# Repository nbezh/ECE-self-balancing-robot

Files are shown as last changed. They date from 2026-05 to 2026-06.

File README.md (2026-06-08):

# Self-Balancing Robot (ESP32)

A two-wheeled self-balancing robot built on an ESP32. The robot keeps itself
upright with a complementary-filter angle estimate feeding a PID controller,
and exposes a WiFi access-point web page for live gain tuning. The firmware is
structured as a set of FreeRTOS tasks.

## Hardware

| Component | Part |
|---|---|
| MCU | ESP32 DevKit (WROOM) |
| Motor driver | TB6612FNG (dual H-bridge) |
| IMU | MPU6050 (GY-521) |
| Distance sensor  | HC-SR04 ultrasonic |
| Motors | TT gearmotors (2x) |
| Power | 8 V pack -> 5 V buck converter|

The IMU is mounted vertically between the wheels; the battery sits high, which
raises the centre of mass and makes the robot tip more slowly (easier to
control).

### Pin map

| Signal | GPIO | Notes |
|---|---|---|
| TB6612 PWMA | 4 | Motor A speed |
| TB6612 AIN2 | 16 | Motor A direction |
| TB6612 AIN1 | 17 | Motor A direction |
| TB6612 BIN1 | 18 | Motor B direction |
| TB6612 BIN2 | 19 | Motor B direction |
| TB6612 PWMB | 23 | Motor B speed |
| TB6612 STBY | 5 | Driver enable. **10 kΩ pulldown to GND** |
| MPU6050 SDA | 21 | I2C (addr 0x68, AD0 -> GND) |
| MPU6050 SCL | 22 | I2C |
| HC-SR04 TRIG | 26 | Direct |
| HC-SR04 ECHO | 25 | **Via 1 kΩ / 2 kΩ divider (5 V -> 3.3 V)** |

GPIO5 is a strapping pin that boots HIGH, so the pulldown keeps the motor
driver disabled at power-up until firmware enables it.

### Power

`8 V -> buck -> 5 V` rail feeds the ESP32 `VIN`, the TB6612 `VM` (motor power),
and the HC-SR04. The ESP32's onboard 3.3 V regulator feeds the TB6612 `VCC`
(logic) and the MPU6050. All grounds are common. A 470–1000 µF bulk capacitor
on the 5 V rail absorbs motor current spikes so the ESP32 doesn't brown out.

> Set the buck to exactly 5.0 V (meter it with the output disconnected) before
> wiring it to the ESP32. Don't power from USB and the buck simultaneously.

## Software

### Build

PlatformIO project. `platformio.ini`:

```ini
[env:esp32dev]
platform = espressif32
board = esp32dev
framework = arduino
monitor_speed = 115200
lib_deps =
    ESP32Async/ESPAsyncWebServer
    ESP32Async/AsyncTCP
build_flags =
    -D CONFIG_ASYNC_TCP_RUNNING_CORE=0
    -D CONFIG_ASYNC_TCP_STACK_SIZE=16384
```

The PWM layer auto-selects the correct LEDC API for ESP32 Arduino core 2.x or
3.x, so it builds on either.

### Run

1. Flash `src/main.cpp`.
2. Connect a phone/laptop to the WiFi network **`BalanceBot`** (password
   `balance123`).
3. Open `http://192.168.4.1`.
4. The robot boots **STOPPED**. Hold it near upright, press **GO** to arm.

The page shows a live angle graph and the latest ultrasonic distance, plus
sliders for Kp, Ki, Kd, balance offset, and the motor deadband. **Save to
flash** persists the current gains (NVS).

## RTOS architecture

The ESP32 Arduino core runs on FreeRTOS, so the firmware is split into three
tasks with explicit priorities and core affinity rather than a single
`loop()`. This separates the one hard-real-time activity (balancing) from the
soft-real-time ones (networking, ranging).

| Task | Core | Priority | Rate | Job |
|---|---|---|---|---|
| `controlTask`  | 1 | 3 (high) | 200 Hz  | MPU read → complementary filter → PID → motors |
| `commsTask` | 0 | 1 | 25 Hz | Push telemetry to the web page |
| `distanceTask` | 0 | 1 | 10 Hz | Read HC-SR04 (`pulseIn`) |

**Deterministic control timing.** `controlTask` uses `vTaskDelayUntil`, which
schedules each iteration on a fixed period instead of "delay N ms after the
work finishes." This gives a constant control interval (`dt = 5 ms`), so the
filter and PID math use a fixed timestep instead of a measured, jittery one.

**Core isolation.** The control task is pinned alone to core 1. The WiFi stack
and the other two tasks live on core 0. Nothing on core 0 can steal time from
the balance loop.

**Why `distanceTask` exists.** `pulseIn()` is a *blocking* call that can stall
for up to 30 ms waiting for the ultrasonic echo. In a single-loop design that
stall would wreck the 200 Hz control timing. Isolating it in its own
low-priority task on core 0 means the blocking read can never disturb
balancing — a concrete demonstration of why task separation matters.

**Synchronization.** All shared data (gains, current angle, run flag, distance)
lives in one `State` struct guarded by a mutex (`stMutex`). Each task takes the
mutex only long enough to *snapshot* values into local variables, then releases
it before doing slow work (motor writes, `ws.textAll()`, `pulseIn`). Critical
sections stay short, so no task blocks another, and there is no nested locking
(no deadlock risk).

```
                 +---------------------+
   web sliders → |  stMutex-guarded    | → controlTask reads gains
                 |  State struct       |
   controlTask → |  (gains, angle,     | → commsTask reads angle/dist
   distanceTask →|   run, distance)    |
                 +---------------------+
```

## Tuning

1. Set the **Offset** to the robot's true balance point: with motors stopped,
   find the angle where it balances on its own on the wheels, read that value
   off the page, and enter it. Usually 1–3°.
2. Set **Min PWM** to the motor deadband — the smallest PWM that actually turns
   the wheels (TT motors ignore small commands below this, so corrections do
   nothing without it).
3. Raise **Kp** until the robot makes firm, quick corrections; add **Kd**
   (~1.0) to damp overshoot; add a little **Ki** last, only if it holds a
   steady lean.

## Known limitations

TT (yellow) gearmotors are marginal for balancing: they have a deadband, gear
backlash, and limited top speed. The deadband compensation helps, but these
motors may set a hard ceiling on how well any tuning can balance the robot.

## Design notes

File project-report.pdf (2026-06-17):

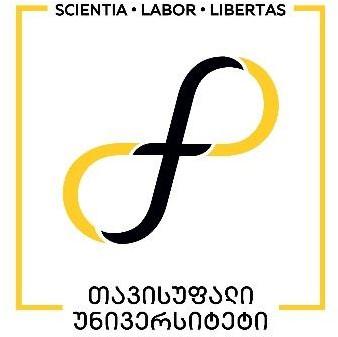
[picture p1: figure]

## თბილისის თავისუფალი უნივერსიტეტი

## კომპიუტერული მეცნიერებების, მათემატიკისა და ინჟინერიის

## სკოლა (MACS[E])

### ელექტრო და კომპიუტერული ინჟინერიის პროგრამა

ბეჟანიშვილი ნიკოლოზ
ცხვედაძე ქეთევანი

ელექტრო და კომპიუტერული ინჟინერიის ლაბორატორია - პროექტის ანგარიში თვითბალანსირებადი რობოტი

თბილისი

2026

ii

## Annotation

This project was completed as part of the “Electrical and Computer Engineering Laboratory”

course. The objective was to design and build a two-wheeled self-balancing robot - a physical

implementation of the inverted pendulum control problem.

The robot uses an MPU6050 six-axis IMU to measure tilt. A complementary filter fuses the

accelerometer and gyroscope readings to estimate the lean angle at 200 Hz. A PID controller converts the

angle error into motor commands delivered to two motored wheels. The firmware is organized as three

concurrent RTOS tasks running across the ESP32’s two cores, separating the hard-real-time balance loop

from soft-real-time networking and sensor tasks. Additional features include HC-SR04 ultrasonic distance

sensing, battery voltage monitoring, and NVS-based persistent gain storage. A WiFi access point exposes

a web interface for live angle telemetry, real-time gain tuning (Kp, Ki, Kd, offset), remote drive control,

and battery voltage display. All primary objectives were achieved: the robot balances stably and all

parameters can be tuned in real time without rebooting.

### ანოტაცია

ეს პროექტი შესრულდა კურსის „ელექტრო და კომპიუტერული ინჟინერიის

ლაბორატორია“ ფარგლებში. პროექტის მიზანი იყო ორბორბლიანი თვითბალანსირებადი

რობოტის შექმნა.

რობოტი იყენებს MPU6050 ექვსღერძიან IMU-ს დახრის გასაზომად. კომპლემენტარული

ფილტრი აერთიანებს აქსელერომეტრისა და გიროსკოპის მონაცემებს 200Hz სიხშირით დახრის

კუთხის შესაფასებლად. PID კონტროლერი კუთხის გადახრის საფუძველზე ატრიალებს ძრავებს

ბალანსის შენარჩუნებლად. პროგრამა სამ პარალელურ RTOS Task-ად არის ორგანიზებული.

WiFi | წვდომის წერტილი | უცრუნველყოფს | ვებ-ინტერფეისს | ტელემეტრიით, | PID-ის

პარამეტრების რეალურ დროში დარეგულირების შესაძლებლობით და დისტანციური მართვით.

ყველა მთავარი მიზანი მიღწეული იქნა.

iii

## Table Of Contents

## Table of Figures

## Introduction

This project was completed as the self-balancing robot assignment for the Electrical and

Computer Engineering Laboratory course at Tbilisi Free University. The goal was to design, build,

and program a two-wheeled self-balancing robot that demonstrates key embedded systems

concepts: sensor fusion, closed-loop control, real-time scheduling, and wireless human-machine

interface design.

The robot is mechanically analogous to a Segway: two driven wheels on a common axle

support a vertical chassis. Without active control, the structure is unstable and will topple. Balance

is maintained by continuously reading the tilt angle from an MPU6050 inertial measurement unit

(IMU), fusing accelerometer and gyroscope measurements through a complementary filter at 200

Hz, and driving TT gearmotors through a TB6612FNG dual H-bridge in the direction that corrects

the lean. The control law is a PID (Proportional-Integral-Derivative) controller.

The firmware runs on an ESP32 microcontroller using the FreeRTOS real-time operating

system, structured as three concurrent tasks with explicit priority and core affinity. The balance-

critical task is isolated on one CPU core; networking and ranging tasks run on the other. This

prevents any soft-real-time activity from disturbing the 5ms control interval.

The robot exposes a WiFi access point. Connecting a phone or laptop to it opens a web

dashboard that shows a live angle graph, the current ultrasonic distance reading, battery voltage,

and sliders for all tunable parameters. Gains can be saved to ESP32 NVS flash so they persist across

power cycles. The chassis was designed in CAD and produced using 3D printing and laser-cut

plywood.

The project had the following requirements:

- Correct Scheme / Wiring: Correctly wiring ESP32, MPU6050, Driver and batteries are

correctly wired.

- Frame and CAD Design: The robot has a systemic construction; the center of mass is

correctly placed and a CAD design of the robot is present.

- Sensor Reading: Reliably reading calibrated values from the MPU6050
- Filtering and Calculating Angle: Filtering IMU data and reliably calculating the lean

angle.

- PID Controller and Tuning: The robot holds balance when turned on and can restore

balance after a small push.

- Radio Control: Remote control using ESP32’s WiFi/Bluetooth, stable connection and

control.

- Object Detection and Avoidance: Detecting object in front using a distance measuring

sensor and avoiding them despite radio commands.

- Telemetry: The remote controller displays the battery charge level, current lean angle

and RSSI WiFi/Bluetooth signal level in real-time.

An additional requirement is that object avoidance and telemetry should run on a separate thread

independent of the control loop using RTOS.

## Technical Review

Physical Design

The chassis is a combination of 3D-printed structural parts and laser-cut plywood for outer

frame. CAD files and G-code are included in the repository under the CAD Files/, 3D Printing/,

and Laser/ subdirectories. The two TT gearmotors are mounted symmetrically on either side of

the lower chassis plate. We mounted MPU6050 IMU between the wheels in a vertical orientation

aligned with the robot’s axis of balance to minimize the error caused by the centripetal and tangential

accelerations. We positioned the battery pack at the top of the chassis. This placement is intentional:

raising the center of mass makes the robot tip more slowly, giving the PID loop more time to react

to disturbances. The power system uses two Li-ion batteries (3.7V nominal, 4.2V max) wired in series

via BMS. The voltage is stepped down to 5 V via a buck converter for ESP and the ultrasonic sensor.

The ESP32’s on-board 3.3 V linear regulator powers the TB6612FNG logic supply (VCC) and the

MPU6050.

We designed the frame in a way that allows for easy assembly using box joints. There are dedicated

holes for wires, switch, motor axis, etc. The files for each piece are stored as individual parts, the full outer

frame of the bot uses these parts and is stored as an assembly and the complete assembly of the bot includes

the frame as well as other hardware. This allows for easier file management and simplifies making changing

due to the architecture of SolidWorks.

### IMU & Angle Estimation

The MPU6050 (GY-521 breakout) is a six-axis IMU providing a three-axis accelerometer

and three-axis gyroscope over I2C. It is powered by the ESP32’s 3.3 V regulator with SDA on

GPIO 21 and SCL on GPIO 22. The AD0 pin is tied to GND, setting the I2C address to 0x68. The

INT, XDA, and XCL pins are left unconnected.

On startup, a gyroscope calibration routine runs while the robot is held stationary. It takes

a fixed number of readings and computes the mean gyroscope output on each axis. These offsets

are subtracted from all subsequent gyro readings, removing static drift bias.

Angle estimation uses a complementary filter. The accelerometer provides an absolute tilt

angle derived from the gravity vector projection, but is noisy due to vibration and motor-induced

acceleration. The gyroscope provides a smooth rate signal that integrates to angle, but accumulates

drift over time. The complementary filter combines both at a fixed 5 ms interval:

angle = α ∗ (angle + gyrorate ∗ dt) + (1 − α) ∗ accel_angle

Where α = 0.98 is the high-pass weight on the gyro path and dt = 5 ms. The filter trusts

the gyroscope for fast dynamics and the accelerometer for slow drift correction. The controlTask

uses vTaskDelayUntil, scheduling each wake-up on a fixed absolute deadline so that dt is exactly

constant regardless of how long the sensor read and math take

### PID Balance Controller

The PID controller runs every 5 ms in controlTask. It computes a motor output from the

angle error as follows:

error = measured_angle − setpoint

integral+= error × dt

output = Kp ∗ error + Ki ∗ integral + Kd ∗

error − preverror
dt

The setpoint (balance offset) compensates for asymmetric component placement where

the robot’s true center of mass does not coincide with the geometric axis. It is calibrated by holding

the robot near vertical, reading the stabilized angle from the web interface, and entering that

value as the offset.

TT gearmotors have a significant stiction deadband: small PWM commands below a

threshold produce no movement due to motor friction and gear backlash. The deadband

compensation adds the configured minimum PWM value to any non-zero output before sending

it to the driver, ensuring that even small corrective commands produce actual wheel movement.

All gains, the balance offset, and the deadband value are stored in the mutex-protected shared

State struct and can be changed via the web interface with immediate effect.

### WiFi Control & Telemetry Interface

The ESP32 operates as a WiFi access point (SSID: BalanceBot, password: balance123),

requiring no external router. ESPAsyncWebServer and AsyncTCP serve a single-page

HTML/JavaScript dashboard at 192.168.4.1 over WebSocket.

The dashboard features a live angle graph updated in real time, the latest ultrasonic

distance reading, battery voltage, sliders for Kp, Ki, Kd, balance offset, and motor deadband, a

GO/STOP button to arm or disarm the balance loop, a Save to Flash button that writes current

gains to ESP32 NVS for persistence across power cycles, and forward/backward drive buttons that

temporarily shift the balance setpoint to command the robot to lean and move.

The commsTask runs at 25 Hz on Core 0, pushing JSON telemetry snapshots to all

connected WebSocket clients. The mutex is held only briefly to copy the current state into local

variables, then released before the WebSocket send, keeping the critical section short.

We used a resistor voltage divider to step the 8.4V battery voltage down into the 0–3.3 V

range readable by the ESP32 ADC. GPIO 35 is used as the ADC input because it is a dedicated

input-only pin with no alternate function conflicts, making it ideal for analog sensing. The divider

is calculated so that the maximum expected battery voltage (nominally 8.4 V for a two-cell lithium

pack at full charge) maps to approximately 3.1 V at the ADC input, staying within the 3.3 V rail

with margin. The ADC reading is converted back to battery voltage by the inverse of the divider

ratio and sent to the web dashboard as part of the commsTask telemetry. We found the values of

47kΩ and 100kΩ to work best for our purposes.

### Distance Detection & Object Avoidance

We used the HC-SR04 Ultrasonic sensor for distance measurement. It measures distance

by emitting a 10 µs pulse on the TRIG pin and timing the return echo on the ECHO pin. Distance

is calculated as:

distance = duration ×

0.034
2
giving the result in centimetres. A pulseIn timeout of 30,000 µs prevents indefinite

blocking when no echo returns.

The HC-SR04 ECHO pin outputs 5V logic. GPIO 25 is protected by a 1 kΩ / 2 kΩ resistor

voltage divider that scales the 5 V echo signal down to approximately 3.3 V before it reaches the

ESP32 input. The pulseIn() call is blocking and can stall for up to 30 ms. In a monolithic loop

design this would destroy the 200 Hz control timing. The solution is to isolate ranging in a

dedicated FreeRTOS task (distanceTask) running at 10 Hz on Core 0 at low priority. The measured

distance is stored in the shared State struct under the mutex, and the control task reads only the

cached value without ever blocking

### FreeRTOS Firmware Architecture

The ESP32 Arduino core runs on FreeRTOS. Rather than a monolithic loop(), the firmware

is organized into three explicit tasks with defined priorities and core affinity, separating the one

hard-real-time activity (balance control) from soft-real-time activities (networking, ranging):

Task | Core | Priority | Rate | Responsibility
controlTask | 1 | 3 (high) | 200 Hz | MPU read → complementary filter → PID → motor output
commsTask | 0 | 1 | 25 Hz | JSON telemetry push to WebSocket clients
distanceTask | 0 | 1 | 10 Hz | HC-SR04 ranging (blocking pulseIn call)

Deterministic control timing is achieved by vTaskDelayUntil in controlTask, which

schedules each wake-up on an absolute tick deadline. This gives a constant dt = 5ms regardless

of how long the IMU read and PID math take. Core isolation pins controlTask alone to Core 1;

nothing on Core 0 can preempt the balance loop.

All shared data lives in a single State struct: the gain values, current angle, armed/run flag,

and ultrasonic distance. The struct is protected by a FreeRTOS mutex (stMutex). Each task

acquires the mutex only long enough to snapshot values into local variables, then releases it before

any slow operation (motor writes, WebSocket sends, pulseIn). This keeps critical sections short

and eliminates nested locking, making deadlock impossible.

## Conclusion

All requirements were met. The robot maintains balance using a complementary filter

angle estimate feeding a PID controller, with all parameters accessible and tunable in real time

through a WiFi web interface without reflashing.

Several engineering challenges were encountered and addressed during development.

Gyroscope drift was mitigated by the startup calibration routine and the complementary filter’s

low-frequency correction from the accelerometer. The blocking nature of pulseIn() was addressed

by isolating ranging in a dedicated low-priority RTOS task so it cannot affect control timing.

The primary hardware limitation of the system is the TT gearmotors. These motors have a

noticeable stiction deadband, gear backlash, and limited maximum speed. The deadband

compensation in the firmware partially addresses the stiction, but gear backlash introduces a

mechanical hysteresis that the control loop cannot fully compensate. Encoderless operation means

there is no closed-loop speed or position feedback at the motor level, which sets a ceiling on

achievable balance quality regardless of PID tuning.

The most valuable learning outcome was the end-to-end design of a real-time embedded

system: understanding how blocking I/O operations must be isolated from time-critical loops, how

shared state must be protected with mutexes in concurrent firmware, and how physical

phenomena (center-of-mass placement, motor stiction, ADC scaling) must be accounted for at

both the hardware and firmware level. The project also provided practical PID tuning experience,

where the interaction between Kp, Kd, and the mechanical deadband became directly observable

through the live web interface.

## Skills and Technologies

- Visual Studio Code (with PlatformIO for ESP programming)
- SolidWorks for CAD design.
- CorelDRAW for editing vector cut designs.
- Programming/markup languages: C++, HTML.
- ESP32 microcontroller programming (C++, Arduino framework, PlatformIO)
- Real-time system design with WebSocket.
- ESPAsyncWebServer and AsyncTCP for WiFi access point and WebSocket server.
- NVS (Non-Volatile Storage) for persistent parameter storage across power cycles.
- FreeRTOS: multi-task firmware design, task priorities, core affinity, vTaskDelayUntil.
- Mutex synchronization for shared state in concurrent firmware
- I2C communication protocol for MPU6050.
- Complementary filter design for IMU sensor fusion
- PID controller design, implementation, and empirical tuning
- Laser Cutting machine competence for cutting out and engraving various designs
- Cable management and labeling, designing maintainable and easily replicable modular systems.
- Physical assembly skills: Soldering, wood cutting & gluing
- Git version control and GitHub repository management with meaningful commit conventions
- Hardware debugging: multimeter use, serial monitor diagnostics, pin conflict resolution

## Individual contributions

Nikoloz Bezhanishvili:

- Mechanical chassis design using SolidWorks
- 3D printing and laser cutting
- Physical assembly, component mounting, and cable management
- Motor mounting and mechanical alignment
- Hardware soldering and wiring
- Project testing, PID tuning, and demonstration preparation
- GitHub repository setup and commit management
- Research
- Project report writing

Ketevani Tskhvedadze:

- Full ESP32 firmware architecture (FreeRTOS task structure, shared State, mutex)
- MPU6050 driver, gyroscope calibration, and complementary filter implementation
- PID controller design and implementation with deadband compensation
- ESPAsyncWebServer WiFi access point and web dashboard (live graph, sliders, drive

control)

- HC-SR04 object detection and avoidance (distanceTask, voltage-divider level shift)
- Battery voltage monitoring circuit (GPIO 35 divider) and firmware integration
- NVS gain persistence implementation
- Hardware soldering and wiring, sensor integration, and debugging
- Research
- Project report writing

## GitHub repository

All source code, CAD files, 3D printing G-code, and laser-cut files for this project are publicly

available on GitHub. The repository is organized into the following subdirectories:

- self-balancing-code/ — PlatformIO project with full C++ firmware
- CAD Files/ — CAD design files for the chassis
- 3D Printing/ — G-code files for 3D-printed structural parts
- Laser/ — Files for laser-cut flat panels

Repository: https://github.com/nbezh/ECE-self-balancing-robot

Contributors’ profiles:

Nikoloz Bezhanishvili – https://github.com/nbezh

Ketevani Tskhvedadze - https://github.com/tskhvedadzee

## References

Datasheets & Component Information:

[1] TDK InvenSense, “MPU-6000 and MPU-6050 Product Specification,” Datasheet. [Online]. Available: https://invensense.tdk.com/wp-content/uploads/2015/02/MPU-6000-Datasheet1.pdf.
[2] Toshiba Semiconductor, “TB6612FNG Dual DC Motor Driver IC,” Datasheet. [Online]. Available: https://www.alldatasheet.com/datasheet-pdf/pdf/209390/TOSHIBA/TB6612FNG.html.
[3] Multicomp, “HC-SR04 Ultrasonic Ranging Module Datasheet,” Alldatasheet. [Online]. Available: https://www.alldatasheet.com/datasheet-pdf/pdf/2216428/MULTICOMP/HC-SR04.html.
[4] Espressif Systems, ESP32 Technical Reference Manual. [Online]. Available: https://documentation.espressif.com/esp32_technical_reference_manual_en.pdf.

Software & Frameworks:

[5] FreeRTOS, “FreeRTOS Kernel Documentation,” FreeRTOS.org. [Online]. Available: https://www.freertos.org/Documentation/01-FreeRTOS-quick-start/01-Beginners-guide/01-RTOSfundamentals. (https://www.freertos.org/Documentation/01-FreeRTOS-quick-start/01-Beginners-guide/01-RTOS-fundamentals)
[6] ESP32Async, “ESPAsyncWebServer,” GitHub. [Online]. Available: https://github.com/ESP32Async/ESPAsyncWebServer.
[7] “PlatformIO Latest Documentation,” PlatformIO. [Online]. Available: https://docs.platformio.org/en/latest/.

Articles & Resources:

[8] Espressif Systems, “Non-Volatile Storage (NVS) Library,” ESP-IDF Documentation. [Online]. Available: https://docs.espressif.com/projects/esp-idf/en/latest/esp32/apireference/storage/nvs_flash.html. (https://docs.espressif.com/projects/esp-idf/en/latest/esp32/api-reference/storage/nvs_flash.html)

GrabCAD 3D Models:

[9] "Perfboard," GrabCAD. [Online]. Available: https://grabcad.com/library/perfboard-1.
[10] "ESP32 DevKit V1 3D Model," GrabCAD. [Online]. Available: https://grabcad.com/library/esp32-devkit-v1-3d-model-1.
[11] "TB6612FNG Driver," GrabCAD. [Online]. Available: https://grabcad.com/library/tb6612fngdriver-1. (https://grabcad.com/library/tb6612fng-driver-1)
[12] "MPU6050 Accelerometer Module," GrabCAD. [Online]. Available: https://grabcad.com/library/mpu6050-accelerometer-module-1.

[13] "HC-SR04 Ultrasonic Sensor," GrabCAD. [Online]. Available: https://grabcad.com/library/hc-sr04-ultrasonic-sensor-10. (https://grabcad.com/library/hc-sr04-ultrasonic-sensor-10)
[14] "Boitier 2 Accus 18650 / 2 Slots 18650 Battery Holder," GrabCAD. [Online]. Available: https://grabcad.com/library/boitier-2-accus-18650-2-slots-18650-battery-holder-1.
[15] "Generic 18650 Battery," GrabCAD. [Online]. Available: https://grabcad.com/library/generic-18650-battery-2. (https://grabcad.com/library/generic-18650-battery-2)
[16] "TT Motor Dual Shaft," GrabCAD. [Online]. Available: https://grabcad.com/library/tt-motordual-shaft-1. (https://grabcad.com/library/tt-motor-dual-shaft-1)
[17] "TT Motor Wheel Yellow," GrabCAD. [Online]. Available: https://grabcad.com/library/tt-motor-wheel-yellow-1. (https://grabcad.com/library/tt-motor-wheel-yellow-1)
[18] "Switch On Off White," GrabCAD. [Online]. Available: https://grabcad.com/library/switch-onoff-white-1. (https://grabcad.com/library/switch-on-off-white-1)

## Attachments & Project Visuals

Table 1: ESP connections

GPIO Board Label | Connected To | Module | Voltage
4 | D4 | TB6612 PWMA | Motor Driver | 3.3V out (PWM)
5 | D5 | TB6612 STBY + 10 kΩ to GND | Motor Driver | 3.3V out
16 | D16 | TB6612 AIN2 | Motor Driver | 3.3V out
17 | D17 | TB6612 AIN1 | Motor Driver | 3.3V out
18 | D18 | TB6612 BIN1 | Motor Driver | 3.3V out
19 | D19 | TB6612 BIN2 | Motor Driver | 3.3V out
23 | D23 | TB6612 PWMB | Motor Driver | 3.3V out (PWM)
21 | D21 | MPU6050 SDA | IMU | 3.3V (I2C)
22 | D22 | MPU6050 SCL | IMU | 3.3V (I2C)
26 | D26 | HC-SR04 TRIG | Distance | 3.3V out
25 | D25 | HC-SR04 ECHO via 1 kΩ/2 kΩ divider | Distance | 3.3V in
35 | D35 (input only) | Battery voltage divider output | Power Monitor | 3.3V in (ADC)
3V3 | 3V3 | MPU6050 VCC, TB6612 VCC | Power | 3.3V source
VIN | VIN | TB6612 VM, HC-SR04 VCC | Power | 5V source
GND | GND | All component GNDs | Power | Ground

Table 2: MPU6050 IMU connections

Pin/Signal | ESP32 GPIO | Notes
VCC | 3V3 | 3.3V supply. MUST be 3.3V; 5V will damage the module
GND | GND | Common ground
SCL | GPIO 22 | I2C clock
SDA | GPIO 21 | I2C data
AD0 | GND | Sets I2C address to 0x68
INT / XDA / XCL | Leave unconnected | Not used in this project

Table 3: TB6612FNG motor driver connections

Pin/Signal | ESP32 GPIO | Notes
PWMA | GPIO 4 | Motor A speed (PWM)
AIN2 | GPIO 16 | Motor A direction
AIN1 | GPIO 17 | Motor A direction
STBY | GPIO 5 | Driver enable. 10 kΩ pulldown to GND keeps LOW during boot
BIN1 | GPIO 18 | Motor B direction
BIN2 | GPIO 19 | Motor B direction
PWMB | GPIO 23 | Motor B speed (PWM)
GND | GND | Common ground
PWMA | GPIO 4 | Motor A speed (PWM)
AIN2 | GPIO 16 | Motor A direction
VM | VIN (5 V) | Motor supply from battery pack
VCC | 3V3 | Logic supply from ESP32 3.3V regulator
AO1/AO2 | — | Left motor
BO1/BO2 | — | Right motor

Table 4: HC-SR04 ultrasonic sensor connections

Pin/Signal | ESP32 GPIO | Notes
VCC | VIN (5 V) | 5V required from buck converter
GND | GND | Common ground
TRIG | GPIO 26 | Output: triggers 10 µs ultrasonic pulse
ECHO | GPIO 25 via 1 kΩ/2 kΩ divider | 5V output scaled to ≈3.3V before ESP32

Table 5: Hand-tuned values

Name | Value | Notes
PID Kp | 34 | One leg to 3.3V
PID Ki | 59 | Other leg to GPIO 33 AND 10kΩ to GND
PID Kd | 0.5 | Voltage divider. Required
PID offset (deg) | 4.3 | Digital output. HIGH when motion detected
Min PWM (deadband) | 48 | 5V required
Voltage divider for Battery reading | 100 kΩ / 47kΩ | Common ground

Table 6: Voltage connections

Voltage | Source | Components Powered | Notes
8 V | Battery pack | Input to buck converter, TB6612 VM | Two-cell lithium: 6.4– 8.4V range
5 V | Buck converter output | ESP32 VIN, HC-SR04 VCC | Set to exactly 5.0V. 470– 1000 µF bulk cap on rail
3.3 V | ESP32 on-board reg. | TB6612 VCC, MPU6050 VCC, GPIO logic | Max ≈500 mA total from ESP32 regulator
Voltage | Source | Components Powered | Notes
8 V | Battery pack | Input to buck converter, TB6612 VM | Two-cell lithium: 6.4– 8.4V range
5 V | Buck converter output | ESP32 VIN, HC-SR04 VCC | Set to exactly 5.0V. 470– 1000 µF bulk cap on rail

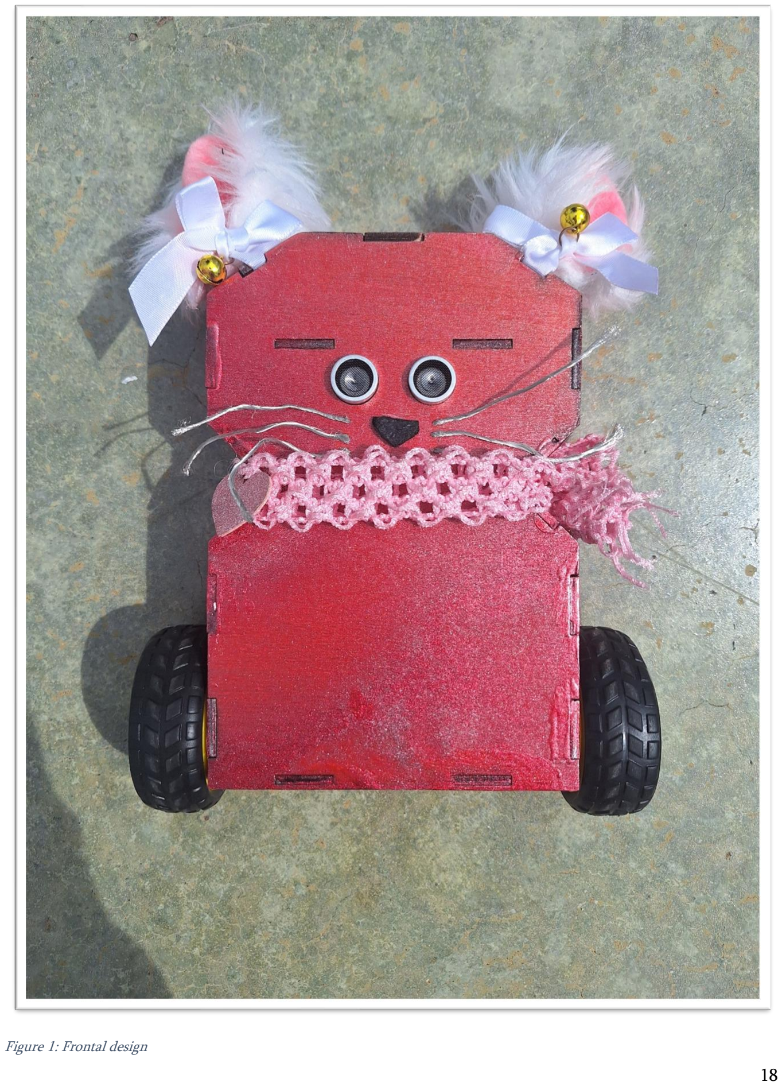
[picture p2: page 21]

Figure

1: Frontal design

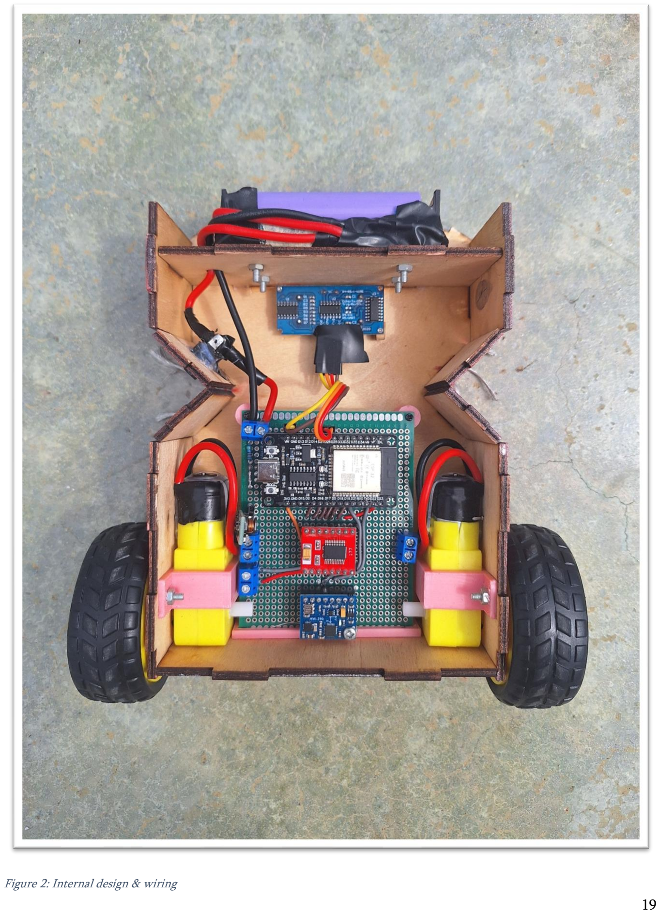
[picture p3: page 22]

Figure

2: Internal design & wiring

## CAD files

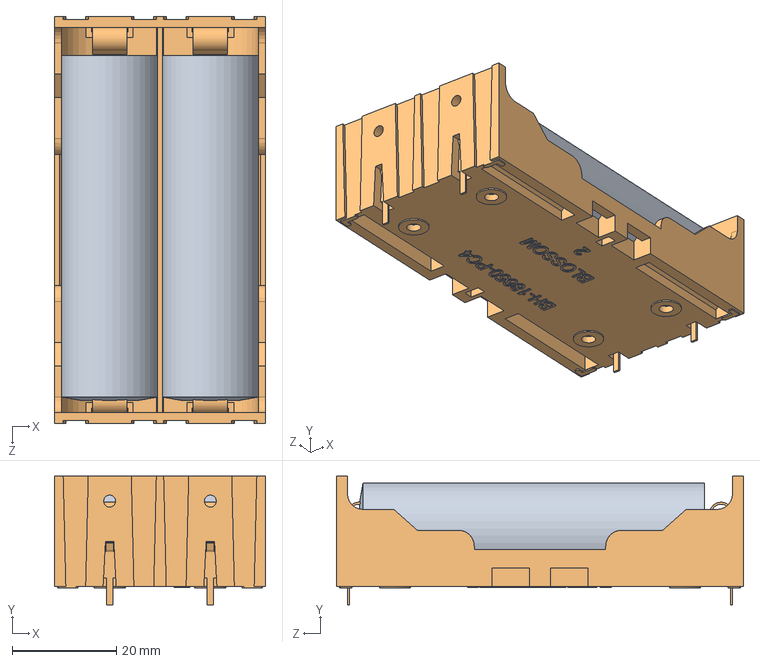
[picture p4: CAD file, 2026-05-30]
CAD Files/Battery Pack/Battery Pack.SLDASM
40.5 x 24.7 x 78.0 mm
Battery holder 2х18650
Generic 18650 Battery v1 x 2

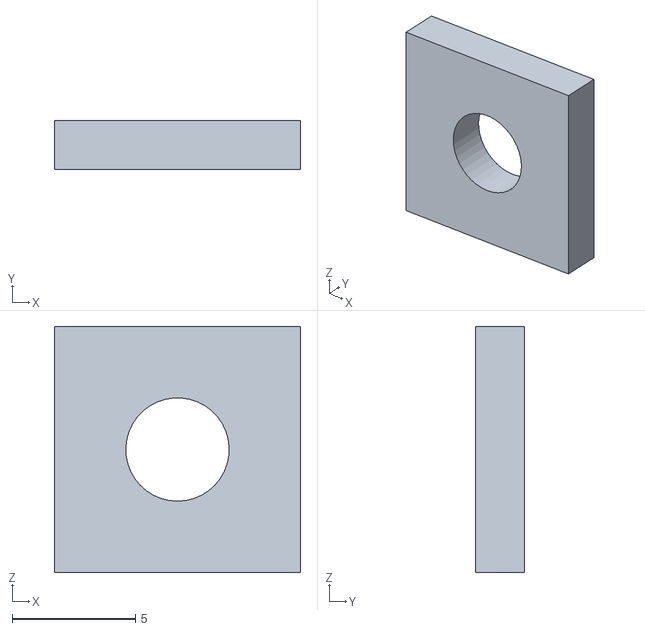
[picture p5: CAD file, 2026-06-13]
3D Printing/magnet holder for cap.STL
10.0 x 2.00 x 10.0

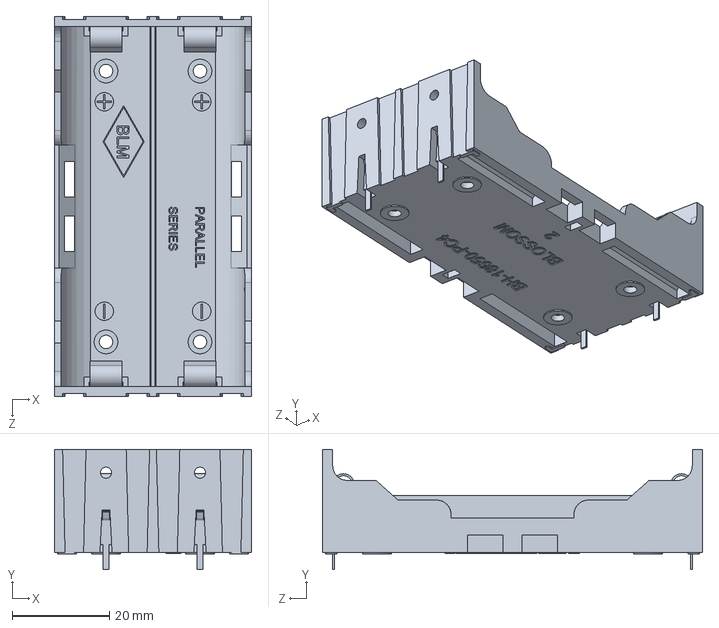
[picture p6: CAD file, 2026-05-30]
CAD Files/Battery Pack/Battery holder 2х18650.SLDPRT
40.5 x 24.7 x 78.0 mm

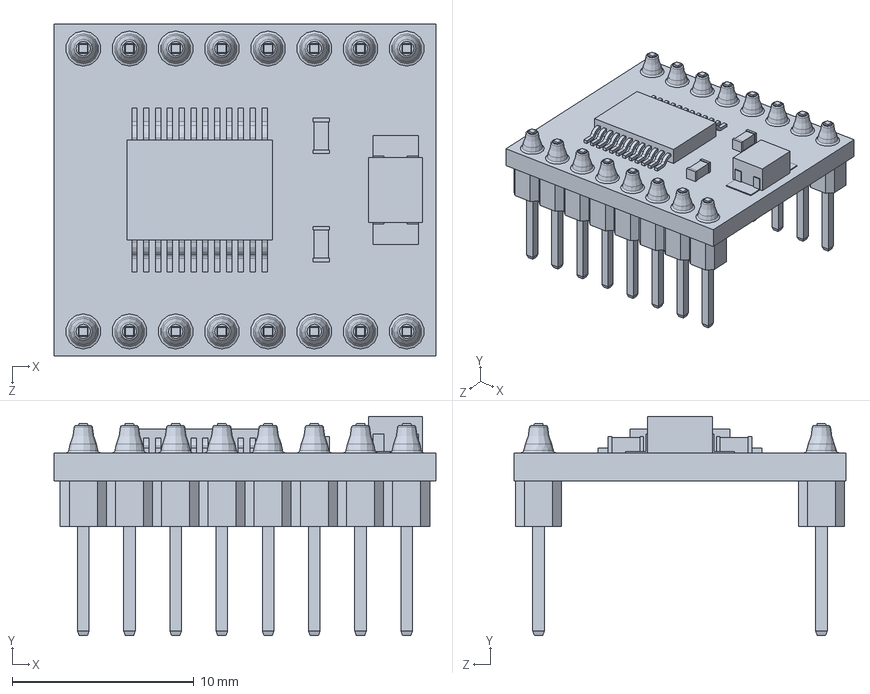
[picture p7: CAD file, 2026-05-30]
CAD Files/Board/TB6612FNG Driver.SLDPRT
21.0 x 12.1 x 18.2 mm

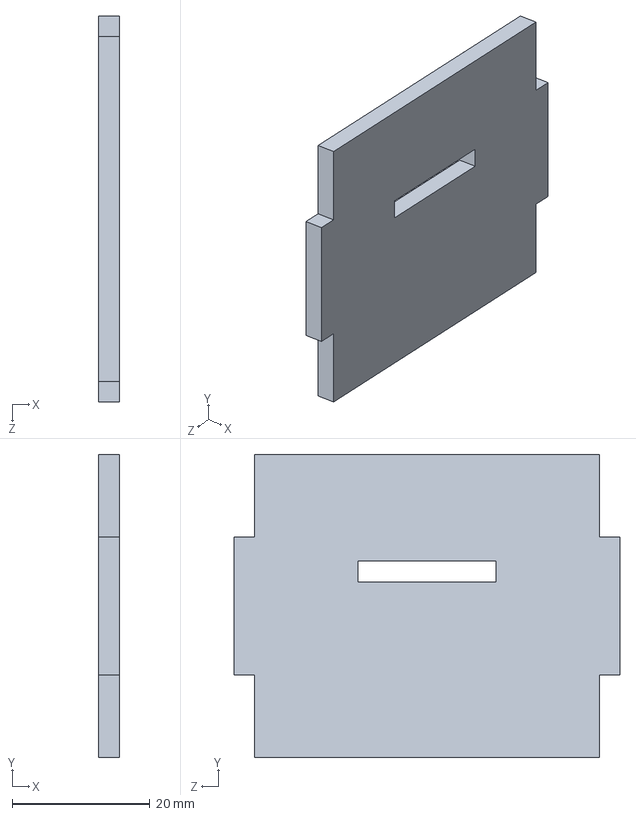
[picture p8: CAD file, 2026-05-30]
CAD Files/Body/Side 3.SLDPRT
3.00 x 44.0 x 56.0 mm

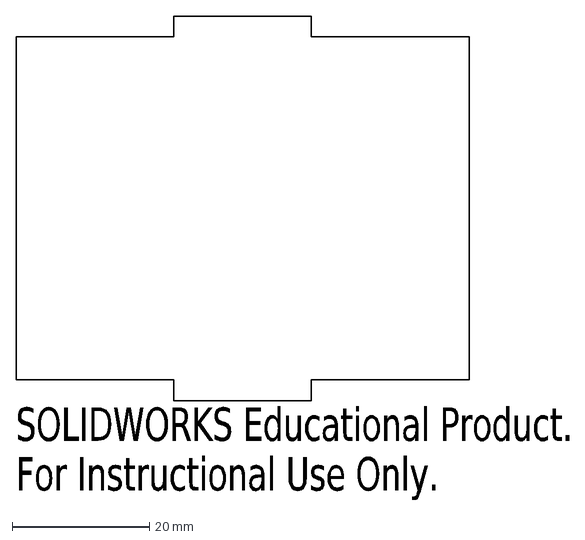
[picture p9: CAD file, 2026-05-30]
Laser/Top.DXF
SOLIDWORKS Educational Product.
For Instructional Use Only.

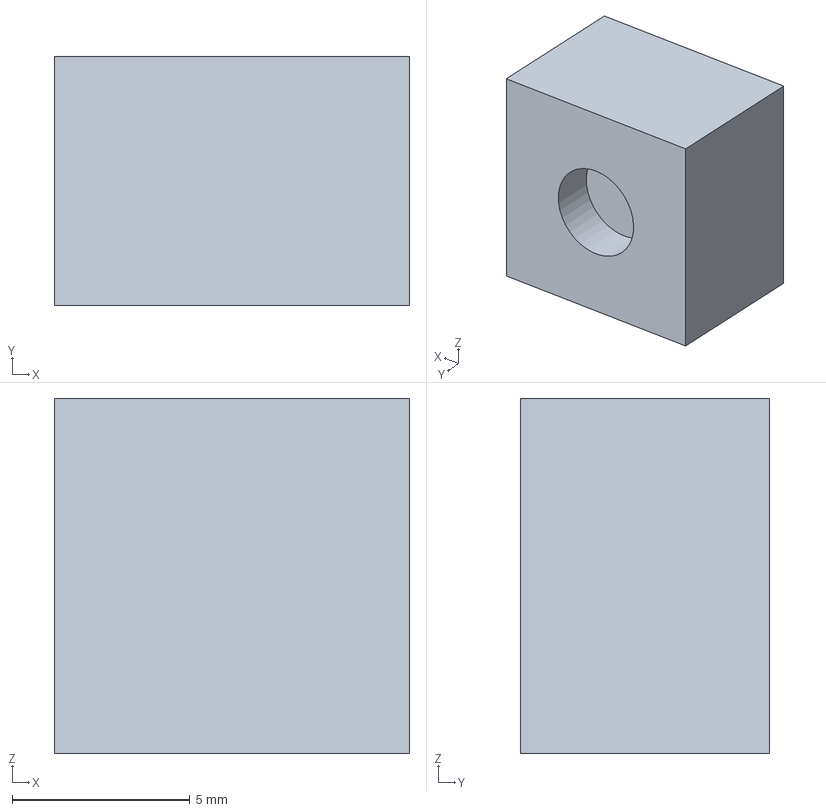
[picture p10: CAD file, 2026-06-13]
3D Printing/magnet holder for base.3MF
10.0 x 7.00 x 10.0 mm

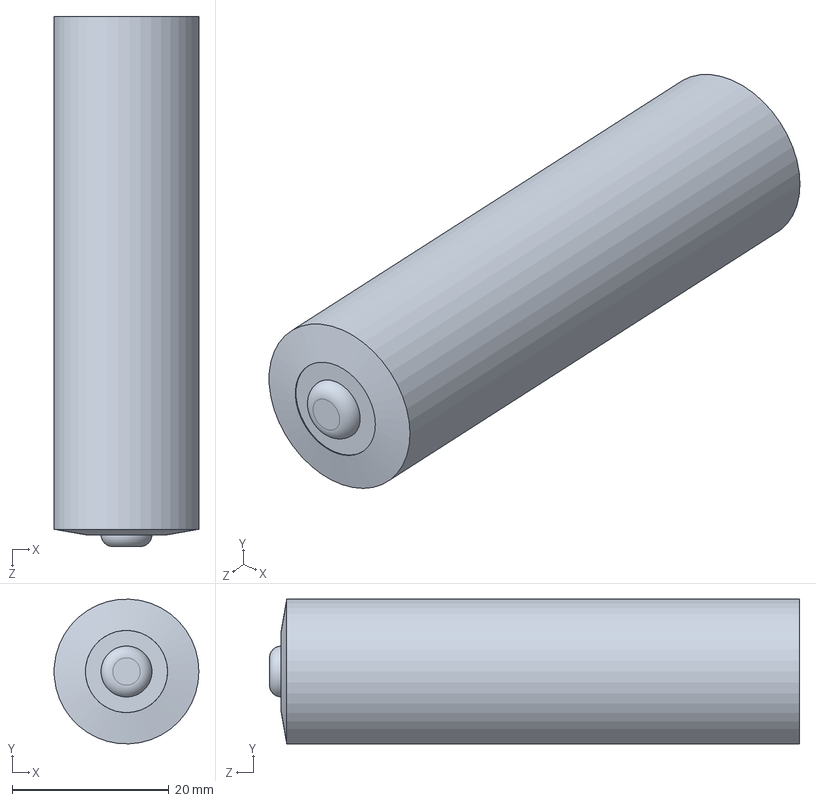
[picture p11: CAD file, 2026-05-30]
CAD Files/Battery Pack/Generic 18650 Battery v1.SLDPRT
18.5 x 18.5 x 67.7 mm

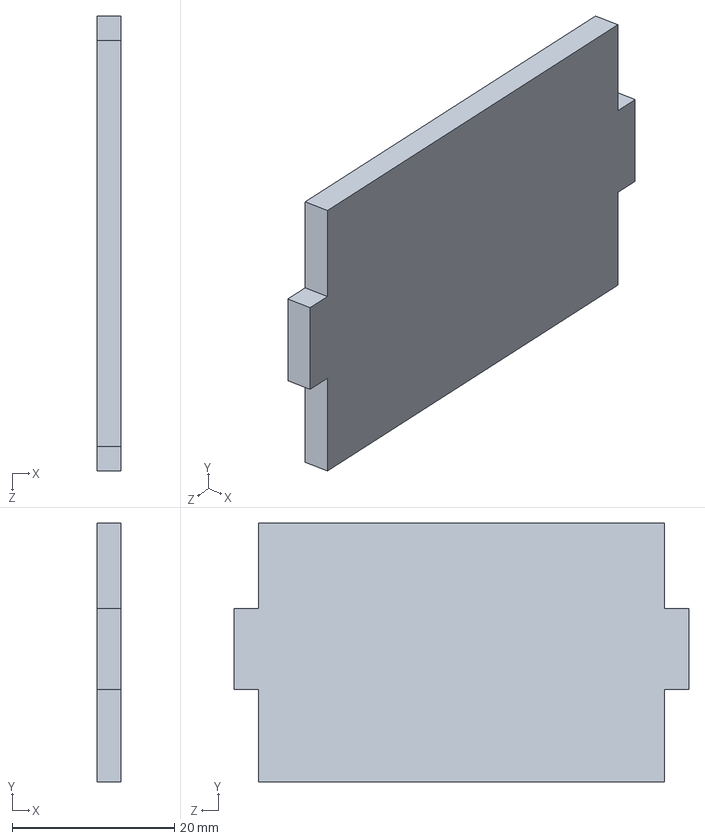
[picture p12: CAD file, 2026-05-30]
CAD Files/Body/Side 4.SLDPRT
3.00 x 31.9 x 56.0 mm

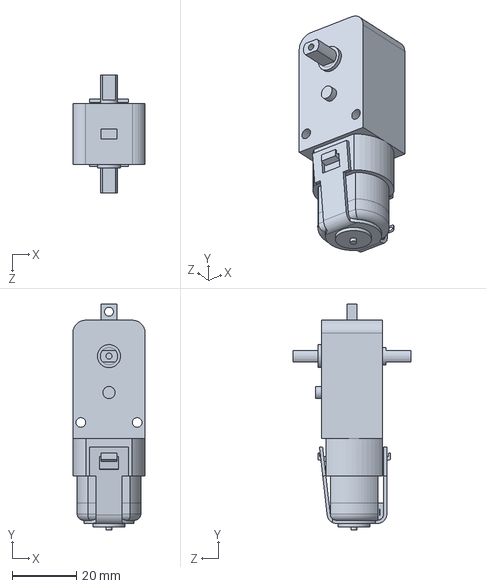
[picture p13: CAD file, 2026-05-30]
CAD Files/Motor and wheel/TT Motor Dual Shaft.SLDPRT
22.5 x 70.2 x 36.8 mm

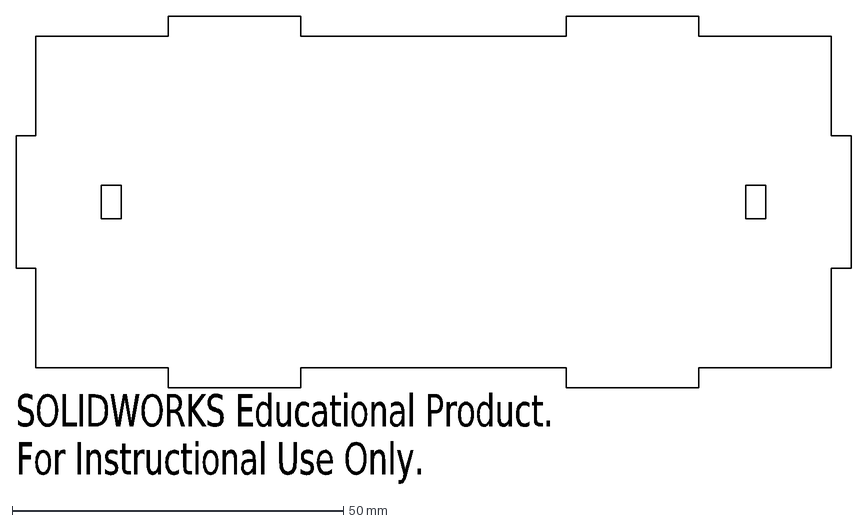
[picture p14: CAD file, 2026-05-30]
Laser/Bottom.DXF
SOLIDWORKS Educational Product.
For Instructional Use Only.

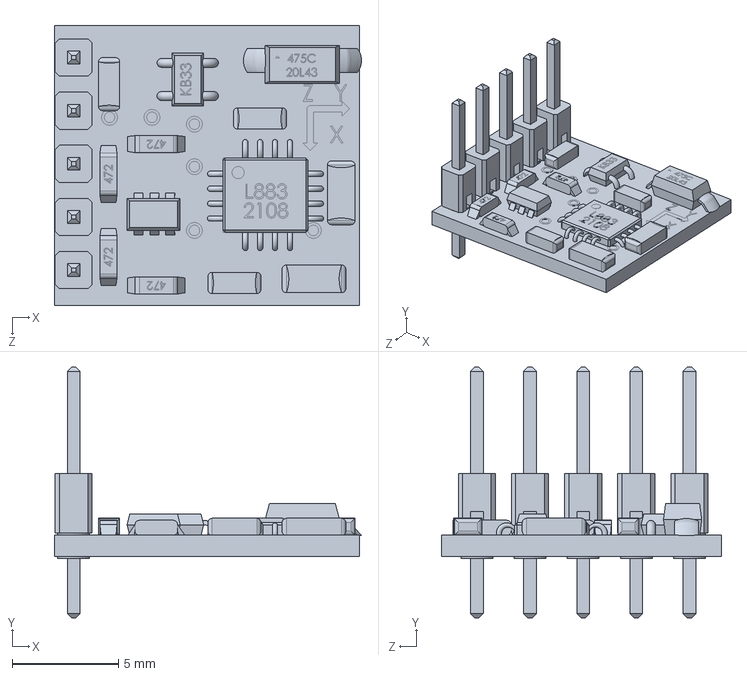
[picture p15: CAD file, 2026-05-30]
CAD Files/Board/HMC5883L Magnetometer.SLDPRT
14.4 x 11.8 x 13.2 mm

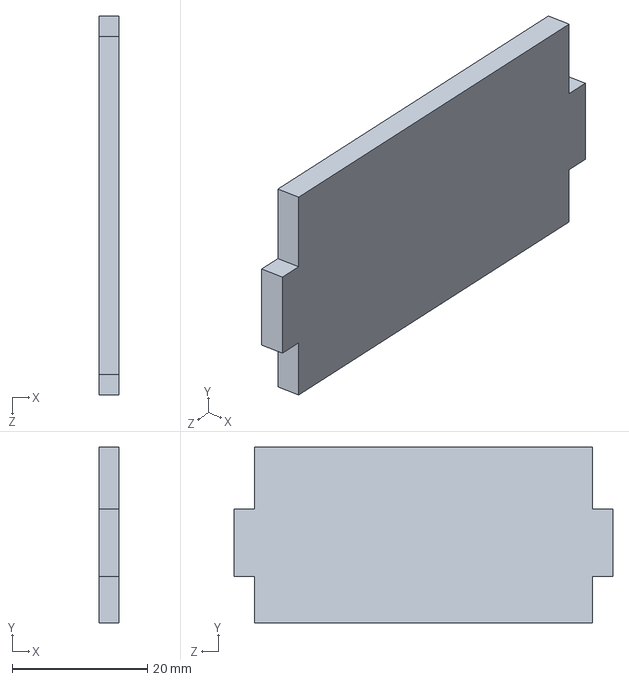
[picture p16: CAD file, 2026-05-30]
CAD Files/Body/Side 2.SLDPRT
3.00 x 26.0 x 56.0 mm

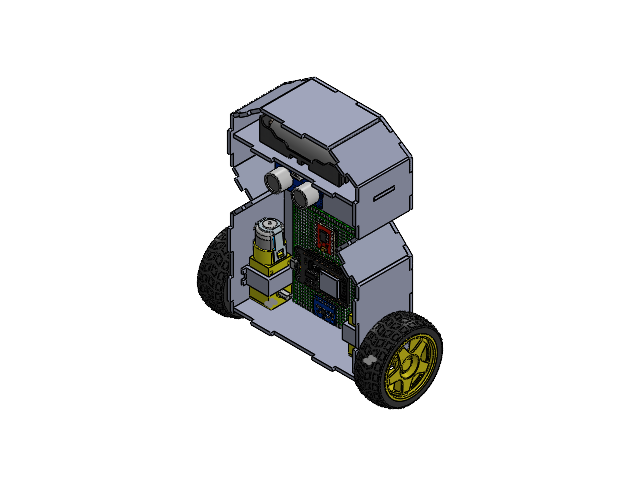
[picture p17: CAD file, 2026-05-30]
CAD Files/Full Assembly.SLDASM
Battery holder 2х18650
Generic 18650 Battery v1 x 2
Yellow Wheel x 2
TT Motor Dual Shaft x 2
Perfboard 90x70
TB6612FNG Driver
ESP32 30pin CH340
MPU6050 Module
Part1^Full Assembly
Bottom
Back
Side 1 x 2
Side 3 x 2
Side 2 x 4
Top
Side 4 x 2
Platform
HCSR04 Ultrasonic Sensor
Motor holder x 2
Switch On_Off

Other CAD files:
CAD Files/Motor and wheel/Motor and wheel.SLDASM
CAD Files/Board/Board.SLDASM
CAD Files/Body/Body.SLDASM
CAD Files/Misc/magnet holder for cap.SLDPRT
3D Printing/Motor holder bottom.STL
3D Printing/Motor holder top.STL
3D Printing/PCB screw holders.3MF
CAD Files/Board/ESP32 30pin CH340.SLDPRT
CAD Files/Board/MPU6050 Module.SLDPRT
CAD Files/Board/Perfboard 90x70.SLDPRT
CAD Files/Body/Back.SLDPRT
CAD Files/Body/Bottom.SLDPRT
CAD Files/Body/Front.SLDPRT
CAD Files/Body/Platform.SLDPRT
CAD Files/Body/Side 1.SLDPRT
CAD Files/Body/Top.SLDPRT
CAD Files/Misc/HCSR04 Ultrasonic Sensor.SLDPRT
CAD Files/Misc/Motor holder.SLDPRT
CAD Files/Misc/PCB screw holders.SLDPRT
CAD Files/Misc/Switch On_Off.SLDPRT
CAD Files/Misc/magnet holder for base.SLDPRT
CAD Files/Motor and wheel/Yellow Wheel.SLDPRT
Laser/Back.DXF
Laser/Front.DXF
Laser/Platform.DXF
Laser/Side 1.DXF
Laser/Side 2.DXF
Laser/Side 3.DXF
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

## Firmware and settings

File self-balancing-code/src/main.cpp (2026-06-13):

/* ============================================================
   Self-Balancing Robot  —  ESP32 + MPU6050 + TB6612FNG
   FreeRTOS version: 3 tasks, mutex-protected shared state.
   + Drive control (WiFi) and battery / RSSI telemetry.
   ------------------------------------------------------------
   RTOS DESIGN
     controlTask  : core 1, prio 3, fixed 200 Hz (vTaskDelayUntil)
                    MPU -> filter -> PID -> motors (+ drive bias/steer).
     commsTask    : core 0, prio 1, 25 Hz. Telemetry + battery + RSSI.
     distanceTask : core 0, prio 1, 10 Hz. HC-SR04 (blocking pulseIn).
     Shared state guarded by a mutex (stMutex).

   DRIVE: web D-pad leans the setpoint (fwd/back) and adds a
          differential to the wheels (left/right). The robot keeps
          balancing while it drives.

   BATTERY: divider on GPIO35 -> 100k (batt+ to pin) + 47k (pin to GND).

   LIBRARIES: ESP32Async/ESPAsyncWebServer + ESP32Async/AsyncTCP
   ============================================================ */

#include <Arduino.h>
#include <WiFi.h>
#include <esp_wifi.h>
#include <AsyncTCP.h>
#include <ESPAsyncWebServer.h>
#include <Wire.h>
#include <Preferences.h>
#include <freertos/FreeRTOS.h>
#include <freertos/task.h>
#include <freertos/semphr.h>

// ---------------- Mode ----------------
#define DIAGNOSTIC 0     // 1 = axis-finding (motors OFF). 0 = balance.

// ---------------- Pin map ----------------
#define PWMA 4
#define AIN2 16
#define AIN1 17
#define STBY 5
#define BIN1 18
#define BIN2 19
#define PWMB 23
#define TRIG 26
#define ECHO 25
#define BATT_PIN 35              // ADC1, input-only, safe with WiFi

#define MPU_ADDR 0x68
const int PWM_FREQ = 20000;
const int PWM_RES  = 8;
#define PWM_CH_A 0
#define PWM_CH_B 1

const float FALL_LIMIT = 45.0;
const float ARM_WINDOW = 3.0;
const float CTRL_DT    = 0.005;          // 200 Hz control period (s)
const float DRIVE_TILT = 1.5;            // deg of setpoint lean per fwd/back press (gentle = keeps balance)
const float DRIVE_RAMP = 0.03;           // how fast the drive lean eases in (per 5 ms cycle)
const int   STEER_PWM  = 40;             // wheel differential per left/right press
const float BATT_DIV   = 0.319;          // R2/(R1+R2) = 47/(100+47); Vbat = Vpin/BATT_DIV
const float OBST_NEAR  = 20.0;           // cm: start backing away below this
const float OBST_FAR   = 30.0;           // cm: stop avoiding once clear past this

// ---------------- Shared state (guarded by stMutex) ----------------
struct State {
  float Kp, Ki, Kd, offset;   // params: web -> control
  int   minPwm, motorDir;
  bool  run;
  int   fb, lr;               // drive: forward/back, left/right (-1,0,1)
  float angle;                // telemetry: control -> comms
  bool  armed;
  float distanceCm;           // distanceTask -> comms
  float battV;                // commsTask
  int   rssi;                 // commsTask
};
State st = { 20.0, 0.0, 0.8, 0.0, 40, -1, false, 0, 0, 0.0, false, -1.0, 0.0, 0 };
SemaphoreHandle_t stMutex;

// ---------------- WiFi AP ----------------
const char* AP_SSID = "BalanceBot";
const char* AP_PASS = "balance123";

AsyncWebServer server(80);
AsyncWebSocket ws("/ws");
Preferences prefs;

// ---------------- Web page ----------------
const char PAGE[] PROGMEM = R"rawliteral(
<!doctype html><html><head><meta charset=utf-8>
<meta name=viewport content="width=device-width,initial-scale=1">
<title>BalanceBot</title><style>
*{box-sizing:border-box}
body{margin:0 auto;padding:20px 14px 40px;max-width:460px;
  font-family:-apple-system,BlinkMacSystemFont,'Segoe UI',Roboto,sans-serif;color:#6b3350;
  background:linear-gradient(165deg,#fff5f9 0%,#ffe8f1 55%,#ffdbe9 100%);min-height:100vh;
  -webkit-tap-highlight-color:transparent}
h1{font-size:23px;font-weight:800;margin:2px 0;color:#e84a8a;text-align:center;letter-spacing:.3px}
.sub{text-align:center;font-size:12px;color:#cf83a8;margin:2px 0 16px;letter-spacing:1px;text-transform:uppercase}
.card{background:#fff;border:1px solid #ffd9e7;border-radius:20px;
  box-shadow:0 8px 22px rgba(255,140,175,.18);padding:15px 16px;margin-bottom:14px}
#stat{font-size:13px;color:#b06088;line-height:1.6;text-align:center}
#stat b{color:#e84a8a;font-size:20px;font-weight:800}
canvas{width:100%;height:150px;background:#fff8fb;border-radius:14px;display:block;border:1px solid #ffe1ec}
.glabel{font-size:11px;color:#cf83a8;text-align:center;margin-top:8px;letter-spacing:1.5px;text-transform:uppercase}
.ttl{font-size:11px;font-weight:800;color:#cf83a8;text-transform:uppercase;letter-spacing:1.5px;margin:0 0 12px;text-align:center}
.row{margin:14px 0}
.row:first-of-type{margin-top:0}
.row:last-of-type{margin-bottom:0}
label{display:flex;justify-content:space-between;font-size:13px;font-weight:700;margin-bottom:9px;color:#9a4f72}
label span{color:#ff5e9a;font-weight:800}
input[type=range]{width:100%;height:8px;border-radius:8px;-webkit-appearance:none;appearance:none;
  background:#ffe0ed;accent-color:#ff5e9a;outline:none;cursor:pointer}
input[type=range]::-webkit-slider-thumb{-webkit-appearance:none;width:22px;height:22px;border-radius:50%;
  background:#ff5e9a;border:3px solid #fff;box-shadow:0 2px 7px rgba(255,94,154,.55)}
input[type=range]::-moz-range-thumb{width:20px;height:20px;border-radius:50%;background:#ff5e9a;border:3px solid #fff}
button{width:100%;padding:15px;font-size:17px;font-weight:800;border:0;border-radius:15px;margin:0;color:#fff;
  background:linear-gradient(135deg,#ff95bd,#ff5e9a);box-shadow:0 6px 15px rgba(255,94,154,.32);cursor:pointer;
  -webkit-user-select:none;-moz-user-select:none;-ms-user-select:none;user-select:none;
  -webkit-touch-callout:none;-webkit-tap-highlight-color:transparent;transition:transform .05s,filter .15s}
button:active{transform:translateY(1px);filter:brightness(.97)}
#go{margin-bottom:14px;letter-spacing:1px}
#go.on{background:linear-gradient(135deg,#ff7a92,#e8417a)}
#save{background:#fff;color:#e84a8a;border:2px solid #ffc6dd;box-shadow:none;font-size:15px}
.pad{display:grid;grid-template-columns:repeat(3,1fr);gap:10px;max-width:230px;margin:0 auto}
.pad button{padding:15px 0;font-size:21px;color:#d6336c;box-shadow:0 4px 11px rgba(255,140,175,.32);
  background:linear-gradient(135deg,#ffd3e3,#ffbcd6);touch-action:none}
.pad #bc{background:linear-gradient(135deg,#ffb0cd,#ff8fb6);color:#fff}
.pad .sp{visibility:hidden;box-shadow:none}
</style></head><body>
<h1>BalanceBot</h1>
<div class=sub>control &amp; tuning</div>
<div class=card><div id=stat>connecting…</div></div>
<div class=card><canvas id=g width=480 height=150></canvas><div class=glabel>tilt angle</div></div>
<button id=go>GO</button>
<div class=card><div class=ttl>drive</div>
<div class=pad>
 <div class=sp></div><button id=bf>&#9650;</button><div class=sp></div>
 <button id=bl>&#9664;</button><button id=bc>&#9632;</button><button id=br>&#9654;</button>
 <div class=sp></div><button id=bb>&#9660;</button><div class=sp></div>
</div></div>
<div class=card><div class=ttl>tuning</div>
<div class=row><label>Kp <span id=vkp></span></label><input type=range id=kp min=0 max=80 step=0.5></div>
<div class=row><label>Ki <span id=vki></span></label><input type=range id=ki min=0 max=400 step=1></div>
<div class=row><label>Kd <span id=vkd></span></label><input type=range id=kd min=0 max=6 step=0.05></div>
<div class=row><label>Offset (deg) <span id=voff></span></label><input type=range id=off min=-12 max=12 step=0.1></div>
<div class=row><label>Min PWM (deadband) <span id=vmp></span></label><input type=range id=mp min=0 max=120 step=1></div>
</div>
<button id=save>Save to flash</button>
<script>
let ws,buf=[],MAXN=240,curRun=false;
const cv=document.getElementById('g'),cx=cv.getContext('2d');
function setS(id,v){const e=document.getElementById(id);e.value=v;document.getElementById('v'+id).textContent=(+v).toFixed(2);}
function send(k,v){if(ws&&ws.readyState==1)ws.send(k+':'+v);}
function draw(){const w=cv.width,h=cv.height,S=30;cx.clearRect(0,0,w,h);
 cx.strokeStyle='#f6cadb';cx.lineWidth=1;cx.beginPath();cx.moveTo(0,h/2);cx.lineTo(w,h/2);cx.stroke();
 cx.strokeStyle='#ff4e8a';cx.lineWidth=2.5;cx.lineJoin='round';cx.beginPath();
 for(let i=0;i<buf.length;i++){const x=i/MAXN*w,y=h/2-(buf[i]/S)*(h/2);i?cx.lineTo(x,y):cx.moveTo(x,y);}cx.stroke();}
function connect(){ws=new WebSocket('ws://'+location.host+'/ws');
 ws.onmessage=e=>{const d=e.data;
  if(d[0]=='s'){const p=d.split(';'),a=parseFloat(p[1]);curRun=p[2]=='1';const armed=p[3]=='1';
   document.getElementById('stat').innerHTML='<b>'+a.toFixed(1)+'\u00B0</b><br>'+(curRun?(armed?'BALANCING':'waiting upright'):'STOPPED')+'<br>dist '+p[4]+'cm &nbsp;&middot;&nbsp; batt '+p[5]+'V &nbsp;&middot;&nbsp; rssi '+p[6]+'dBm';
   buf.push(a);if(buf.length>MAXN)buf.shift();draw();
   const go=document.getElementById('go');go.textContent=curRun?'STOP':'GO';go.className=curRun?'on':'';}
  else if(d[0]=='c'){const p=d.split(';');setS('kp',p[1]);setS('ki',p[2]);setS('kd',p[3]);setS('off',p[4]);setS('mp',p[5]);}};
 ws.onclose=()=>setTimeout(connect,1000);}
['kp','ki','kd','off','mp'].forEach(id=>{const e=document.getElementById(id);
 e.oninput=()=>{document.getElementById('v'+id).textContent=(+e.value).toFixed(2);send(id,e.value);};});
document.getElementById('go').onclick=()=>send('run',curRun?0:1);
document.getElementById('save').onclick=()=>{if(ws&&ws.readyState==1)ws.send('save');};
function hold(id,k,v){const e=document.getElementById(id);
 const on=ev=>{ev.preventDefault();send(k,v);};
 const off=ev=>{ev.preventDefault();send(k,0);};
 e.addEventListener('pointerdown',on);e.addEventListener('pointerup',off);
 e.addEventListener('pointerleave',off);e.addEventListener('pointercancel',off);}
hold('bf','fb',1);hold('bb','fb',-1);hold('bl','lr',-1);hold('br','lr',1);
document.getElementById('bc').onclick=()=>{send('fb',0);send('lr',0);};
connect();
</script></body></html>
)rawliteral";

// ============================================================
//  MPU6050
// ============================================================
void mpuWrite(uint8_t reg, uint8_t val){
  Wire.beginTransmission(MPU_ADDR); Wire.write(reg); Wire.write(val); Wire.endTransmission();
}
void mpuInit(){
  mpuWrite(0x6B,0x00); delay(100);
  mpuWrite(0x1A,0x03); mpuWrite(0x1B,0x00); mpuWrite(0x1C,0x00);
}
void mpuRead(int16_t &ax,int16_t &ay,int16_t &az,int16_t &gx,int16_t &gy,int16_t &gz){
  Wire.beginTransmission(MPU_ADDR); Wire.write(0x3B); Wire.endTransmission(false);
  Wire.requestFrom(MPU_ADDR,14,true);
  ax=(Wire.read()<<8)|Wire.read(); ay=(Wire.read()<<8)|Wire.read(); az=(Wire.read()<<8)|Wire.read();
  Wire.read(); Wire.read();
  gx=(Wire.read()<<8)|Wire.read(); gy=(Wire.read()<<8)|Wire.read(); gz=(Wire.read()<<8)|Wire.read();
}

// ============================================================
//  Motors  (PWM works on core 2.x channel API and 3.x pin API)
// ============================================================
void pwmSetup(){
#if ESP_ARDUINO_VERSION_MAJOR >= 3
  ledcAttach(PWMA, PWM_FREQ, PWM_RES);
  ledcAttach(PWMB, PWM_FREQ, PWM_RES);
#else
  ledcSetup(PWM_CH_A, PWM_FREQ, PWM_RES); ledcAttachPin(PWMA, PWM_CH_A);
  ledcSetup(PWM_CH_B, PWM_FREQ, PWM_RES); ledcAttachPin(PWMB, PWM_CH_B);
#endif
}
inline void pwmA(int d){
#if ESP_ARDUINO_VERSION_MAJOR >= 3
  ledcWrite(PWMA, d);
#else
  ledcWrite(PWM_CH_A, d);
#endif
}
inline void pwmB(int d){
#if ESP_ARDUINO_VERSION_MAJOR >= 3
  ledcWrite(PWMB, d);
#else
  ledcWrite(PWM_CH_B, d);
#endif
}
void motorsEnable(bool on){ digitalWrite(STBY, on?HIGH:LOW); }
void motorA(int speed){ bool f=(speed>=0); int s=constrain(abs(speed),0,255);
  digitalWrite(AIN1,f?HIGH:LOW); digitalWrite(AIN2,f?LOW:HIGH); pwmA(s); }
void motorB(int speed){ bool f=(speed>=0); int s=constrain(abs(speed),0,255);
  digitalWrite(BIN1,f?HIGH:LOW); digitalWrite(BIN2,f?LOW:HIGH); pwmB(s); }

// ============================================================
//  Preferences
// ============================================================
void loadPrefs(){
  prefs.begin("balance", true);
  st.Kp=prefs.getFloat("kp",st.Kp); st.Ki=prefs.getFloat("ki",st.Ki);
  st.Kd=prefs.getFloat("kd",st.Kd); st.offset=prefs.getFloat("off",st.offset);
  st.minPwm=prefs.getInt("mp",st.minPwm);
  prefs.end();
}
void savePrefs(){
  float kp,ki,kd,off; int mp;
  xSemaphoreTake(stMutex,portMAX_DELAY);
  kp=st.Kp; ki=st.Ki; kd=st.Kd; off=st.offset; mp=st.minPwm;
  xSemaphoreGive(stMutex);
  prefs.begin("balance", false);
  prefs.putFloat("kp",kp); prefs.putFloat("ki",ki); prefs.putFloat("kd",kd);
  prefs.putFloat("off",off); prefs.putInt("mp",mp);
  prefs.end();
}

// ============================================================
//  Telemetry helpers
// ============================================================
float readBattery(){
  uint32_t sum=0; const int N=32;
  for(int i=0;i<N;i++) sum += analogReadMilliVolts(BATT_PIN);  // oversample
  float vbat = ((sum/(float)N)/1000.0f) / BATT_DIV;
  static float filt = -1;
  filt = (filt < 0) ? vbat : (filt*0.9f + vbat*0.1f);          // EMA smoothing
  return filt;
}
int apRssi(){                       // RSSI of first connected station (we are the AP)
  wifi_sta_list_t sl;
  if(esp_wifi_ap_get_sta_list(&sl) == ESP_OK && sl.num > 0) return sl.sta[0].rssi;
  return 0;
}

// ============================================================
//  WebSocket
// ============================================================
void handleMsg(const String &m){
  int c=m.indexOf(':');
  if(c<0){ if(m=="save") savePrefs(); return; }
  String k=m.substring(0,c); float v=m.substring(c+1).toFloat();
  xSemaphoreTake(stMutex,portMAX_DELAY);
  if(k=="kp")st.Kp=v; else if(k=="ki")st.Ki=v; else if(k=="kd")st.Kd=v;
  else if(k=="off")st.offset=v; else if(k=="mp")st.minPwm=(int)v;
  else if(k=="fb")st.fb=(int)v; else if(k=="lr")st.lr=(int)v;
  else if(k=="run"){ st.run=(v!=0); if(!st.run){ st.fb=0; st.lr=0; } }
  xSemaphoreGive(stMutex);
}
void onWsEvent(AsyncWebSocket*s,AsyncWebSocketClient*client,AwsEventType type,void*arg,uint8_t*data,size_t len){
  if(type==WS_EVT_CONNECT){
    float kp,ki,kd,off; int mp;
    xSemaphoreTake(stMutex,portMAX_DELAY);
    kp=st.Kp;ki=st.Ki;kd=st.Kd;off=st.offset;mp=st.minPwm;
    xSemaphoreGive(stMutex);
    String cfg="c;"+String(kp,2)+";"+String(ki,2)+";"+String(kd,2)+";"+String(off,2)+";"+String(mp);
    client->text(cfg);
  } else if(type==WS_EVT_DATA){
    AwsFrameInfo*info=(AwsFrameInfo*)arg;
    if(info->final && info->index==0 && info->len==len && info->opcode==WS_TEXT){
      String msg; msg.reserve(len);
      for(size_t i=0;i<len;i++) msg+=(char)data[i];
      handleMsg(msg);
    }
  }
}

// ============================================================
//  TASKS
// ============================================================

// --- Control task: hard real-time, core 1, 200 Hz ---
void controlTask(void *pv){
  static float angle=0, integral=0;
  static bool armed=false;
  static float gyBias=0;

  // gyro-bias calibration: keep the robot STILL for ~1.6 s at boot
  Serial.println("Calibrating gyro - hold still...");
  { long gsum=0; const int N=800; int16_t ax,ay,az,gx,gy,gz;
    for(int i=0;i<N;i++){ mpuRead(ax,ay,az,gx,gy,gz); gsum+=gy; delay(2); }
    gyBias=(float)gsum/N;
    Serial.printf("gyro bias gy=%.1f\n", gyBias);
    angle = atan2((float)az, -(float)ax) * 57.29578f; }     // seed
  TickType_t last = xTaskGetTickCount();
  for(;;){
    int16_t ax,ay,az,gx,gy,gz; mpuRead(ax,ay,az,gx,gy,gz);

#if DIAGNOSTIC
    motorsEnable(false); motorA(0); motorB(0);
    static uint32_t lr=0;
    if(millis()-lr>100){ lr=millis();
      Serial.printf("ax=%d ay=%d az=%d | gx=%d gy=%d gz=%d\n",ax,ay,az,gx,gy,gz); }
#else
    // [AXIS] gravity=X, tilt=Z, rotation=Y (gyro sign flipped: -gy)
    float accAngle = atan2((float)az, -(float)ax) * 57.29578f;
    float gyroRate = -((float)gy - gyBias) / 131.0f;
    angle = 0.98f*(angle + gyroRate*CTRL_DT) + 0.02f*accAngle;

    // snapshot params + drive commands
    float Kp,Ki,Kd,offset; int minPwm,dir,fb,lr; bool run; float dist;
    xSemaphoreTake(stMutex,portMAX_DELAY);
    Kp=st.Kp; Ki=st.Ki; Kd=st.Kd; offset=st.offset;
    minPwm=st.minPwm; dir=st.motorDir; run=st.run; fb=st.fb; lr=st.lr;
    dist=st.distanceCm;
    xSemaphoreGive(stMutex);

    // obstacle avoidance: back away from anything close ahead, overriding the
    // radio command. Hysteresis (NEAR/FAR) stops it chattering at the edge.
    static bool avoiding=false;
    if(dist>0 && dist<OBST_NEAR)       avoiding=true;
    else if(dist<0 || dist>OBST_FAR)   avoiding=false;
    if(avoiding) fb=-dir;                 // lean back -> drive away from obstacle

    // ease the drive lean in/out so fwd/back accelerates gently and keeps balance
    static float driveBias=0;
    driveBias += (fb*DRIVE_TILT - driveBias) * DRIVE_RAMP;

    float target = offset + driveBias;   // gentle lean to drive fwd/back

    if(!run){
      armed=false; integral=0; motorsEnable(false); motorA(0); motorB(0);
    } else if(fabs(angle)>FALL_LIMIT){
      armed=false; integral=0; motorsEnable(false); motorA(0); motorB(0);
    } else if(!armed && fabs(angle-offset)<ARM_WINDOW){
      armed=true; integral=0; motorsEnable(true);
    }

    if(run && armed){
      float error=target-angle;
      integral+=error*CTRL_DT; integral=constrain(integral,-200,200);
      float output=Kp*error + Ki*integral - Kd*gyroRate;
      output=constrain(output,-255,255);
      int drive=(int)output;
      if(drive>1) drive+=minPwm; else if(drive<-1) drive-=minPwm;
      drive=constrain(drive,-255,255)*dir;
      int steer=lr*STEER_PWM;                 // differential for turning
      int left =constrain(drive+steer,-255,255);
      int right=constrain(drive-steer,-255,255);
      motorA(left); motorB(right);
    } else if(run){
      motorA(0); motorB(0);
    }

    // publish telemetry
    xSemaphoreTake(stMutex,portMAX_DELAY);
    st.angle=angle; st.armed=armed;
    xSemaphoreGive(stMutex);
#endif
    vTaskDelayUntil(&last, pdMS_TO_TICKS(5));   // exact 200 Hz
  }
}

// --- Comms task: telemetry to web, core 0, 25 Hz ---
void commsTask(void *pv){
  for(;;){
    float vbat = readBattery();
    int   r    = apRssi();
    float a,d; bool run,armed;
    xSemaphoreTake(stMutex,portMAX_DELAY);
    st.battV=vbat; st.rssi=r;
    a=st.angle; run=st.run; armed=st.armed; d=st.distanceCm;
    xSemaphoreGive(stMutex);
    ws.cleanupClients();
    String m="s;"+String(a,2)+";"+String(run?1:0)+";"+String(armed?1:0)+";"
             +String(d,0)+";"+String(vbat,2)+";"+String(r);
    ws.textAll(m);
    vTaskDelay(pdMS_TO_TICKS(40));
  }
}

// --- Distance task: blocking HC-SR04 isolated here, core 0, 10 Hz ---
void distanceTask(void *pv){
  for(;;){
    digitalWrite(TRIG,LOW);  delayMicroseconds(2);
    digitalWrite(TRIG,HIGH); delayMicroseconds(10); digitalWrite(TRIG,LOW);
    unsigned long us = pulseIn(ECHO, HIGH, 30000UL);   // blocks up to 30 ms
    float cm = us ? us/58.0f : -1.0f;
    xSemaphoreTake(stMutex,portMAX_DELAY);
    st.distanceCm=cm;
    xSemaphoreGive(stMutex);
    vTaskDelay(pdMS_TO_TICKS(100));
  }
}

// ============================================================
//  Setup / loop
// ============================================================
void setup(){
  Serial.begin(115200);
  pinMode(STBY,OUTPUT); digitalWrite(STBY,LOW);
  pinMode(AIN1,OUTPUT); pinMode(AIN2,OUTPUT); pinMode(BIN1,OUTPUT); pinMode(BIN2,OUTPUT);
  pwmSetup(); motorA(0); motorB(0);
  pinMode(TRIG,OUTPUT); pinMode(ECHO,INPUT);
  analogReadResolution(12);

  Wire.begin(); Wire.setClock(400000); mpuInit();

  stMutex = xSemaphoreCreateMutex();
  loadPrefs();

  WiFi.mode(WIFI_AP);
  WiFi.softAP(AP_SSID, AP_PASS);
  Serial.print("AP IP: "); Serial.println(WiFi.softAPIP());

  ws.onEvent(onWsEvent);
  server.addHandler(&ws);
  server.on("/", HTTP_GET, [](AsyncWebServerRequest*r){ r->send_P(200,"text/html",PAGE); });
  server.begin();

  // priority: control(3) > comms(1)=distance(1).  core 1 = control only.
  xTaskCreatePinnedToCore(controlTask,  "control",  4096, NULL, 3, NULL, 1);
  xTaskCreatePinnedToCore(commsTask,    "comms",    4096, NULL, 1, NULL, 0);
  xTaskCreatePinnedToCore(distanceTask, "distance", 2048, NULL, 1, NULL, 0);
}

void loop(){
  vTaskDelay(pdMS_TO_TICKS(1000));   // nothing here; work is in the tasks
}

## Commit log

2026-05-26 imported cad components
    [Battery Pack.SLDASM, Battery holder 2х18650.SLDPRT, Board.SLDASM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]
2026-05-26 designed robot body
    [Part18.SLDPRT]
2026-05-28 designed new robot body
    [Back.SLDPRT, Body.SLDASM, Bottom.SLDPRT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]
2026-05-28 updated full assembly
    [Back.SLDPRT, Board.SLDASM, Body.SLDASM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]
2026-05-28 added motor holder
    [Full Assembly.SLDASM, Motor and wheel.SLDASM, Motor holder.SLDPRT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]
2026-05-29 adjusted dimensions
    [Back.SLDPRT, Board.SLDASM, Body.SLDASM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]
2026-05-29 Added .dxf files of the faces
    [Back.DXF, Bottom.DXF, Front.DXF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]
2026-05-29 added corel file for laser cutting
2026-05-29 added 3d printing files
    [Full Assembly.SLDASM, Motor holder bottom.STL, Motor holder top.STL]
2026-05-30 added switch
    [Back.SLDPRT, Body.SLDASM, Full Assembly.SLDASM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]
2026-06-08 Add self-balancing robot firmware (ESP32 + MPU6050 + TB6612FNG)
    - Complementary filter + PID balance loop
    - WiFi AP live-tuning page: Kp/Ki/Kd/offset/deadband sliders, live graph, GO/STOP, save to flash
    - Version-agnostic LEDC PWM (core 2.x/3.x)
    - Motor deadband compensation for TT motors
    - DIAGNOSTIC axis-finding mode
2026-06-08 Restructure firmware into FreeRTOS tasks
    control task on core 1 (200 Hz), comms + distance on core 0, mutex-guarded shared state
2026-06-11 Improve motor control, balancing, and drive tuning
2026-06-13 add magnet holders
    [PCB screw holders.3MF, PCB screw holders.SLDPRT, magnet holder for base.3MF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]
